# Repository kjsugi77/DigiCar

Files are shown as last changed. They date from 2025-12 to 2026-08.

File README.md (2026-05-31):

## 構成フォルダ
- program/        ← 車両制御プログラム（C++）
- electronics/    ← 基板データ（KiCad / Gerber / 回路図PDF）
- 3d_print/       ← 3Dプリント用データ（STL）
- parts/          ← 部品表（BOM）

---

# DigiCar（デジカー）

DigiCar は、ミニ四駆サイズの学習用自動運転ミニカーです。  
プリント基板そのものがシャーシとなる独自構造を採用し、  
RumiCar をリスペクトした教育向けプラットフォームとして開発されています。

2025年8月30日の「デジもく会」にて正式発表されました。

---

## 特徴

- プリント基板がシャーシとして機能する独自構造
- 自動運転機能を搭載予定（ToF センサ対応）
- Bluetooth をメインとした無線通信
- 教育教材としての普及を目指した低コスト設計（想定金額 約5,000円）

---

## システム構成

DigiCar は **電気系・プログラム・機械系** の 3 要素で構成されています。

### ● 電気系
- マイコン：ESP32-WROOM-32E  
- モータードライバ：TB6612FNG（東芝）  
- 電圧レギュレータ：TC1262-3.3VDB05（Microchip）  
- USBシリアル変換：FT231XS（FTDI）  
- 通信方式：Bluetooth（メイン）、Wi-Fi（サブ）

### ● プログラム
- 使用言語：C++（Arduino IDE）

### ● 機械系
- ステアリング：SG-90 サーボモータ  
- 駆動モータ：マブチ FA-130  
- ギア・シャフト・タイヤ：タミヤ製を中心に構成  
- 3Dプリント部品：ギヤケース、ステアリング機構、電池ケース固定部品など

---

## 開発ストーリー

### 2020年〜：胎動（暗黒時代）
N氏による構想が始まるも、具体化せず停滞。

### 2024年2月：運命の再始動
デジもく会で H氏の「基板、作りませんか？」の一言から再燃。

### 2025年3〜5月：継承と本格始動
京都NTで試作モックを受領し、開発が本格化。

### 2025年8〜9月：公開とコミュニティ化
初発表で手応えを掴み、はんだ付け会や Discord 開設へ。

### 2025年10〜11月：危機と復活
通信不良・異常電流の問題を発見。配線ミスを特定し、改良基板で復活。

### 2026年2月〜現在：次のステージへ
サンプル3台を提供し、マニュアル操作アプリも完成。  
現在は ToF センサ搭載による自動運転へ挑戦中。

---

## コスト構成（概算：ToF センサ除く 約 4,000 円）

### 1. 電気・電子部品（約 1,500 円）
- ESP32-WROOM-32E：約 800 円  
- FT231XS：約 320 円  
- TB6612FNG：約 200 円  
- その他：基板、抵抗・コンデンサ類

### 2. 駆動・メカ部品（約 1,000 円強）
- SG-90 サーボ：650 円  
- ギヤ・シャフト・タイヤ類：約 400 円  
- 3Dプリント部品、ネジ類

### 3. 電源（約 1,000 円強）
- エネループライト（単4×4本）：約 1,000 円  
- 電池ボックス（スイッチ付）：100 円

### 4. その他
- 基板（JLCPCB）：約 100 円

---

## ライセンス

本リポジトリは **MIT License** のもとで公開されています。

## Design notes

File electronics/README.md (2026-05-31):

# electronics フォルダについて

DigiCar の電装・基板データをまとめたフォルダです。  
基板設計（KiCad）、製造用データ（Gerber）、回路図（PDF）を用途別に整理しています。

## フォルダ構成

electronics/
├── kicad/               ← KiCad プロジェクト一式（.kicad_pcb / .sch など）
├── gerber/              ← 基板製造用データ（Gerber ファイル）
└── schematic/           ← 回路図（PDF など）

## 使い方

- **kicad/**  
  基板の編集・修正を行う場合に使用します。  
  KiCad でプロジェクトを開くと、回路図と PCB を編集できます。

- **gerber/**  
  基板製造業者にそのまま提出できるデータです。  
  製造依頼時はこのフォルダ内の ZIP を使用します。

- **schematic/**  
  回路図を PDF で確認したい場合に使用します。  
  アプリ開発者や他のメンバーが電装仕様を理解する際にも便利です。

# About the electronics folder

This folder contains all electronic and PCB-related data for the DigiCar project.  
The contents are organized by purpose: PCB design (KiCad), manufacturing data (Gerber), and circuit diagrams (PDF).

## Folder Structure

electronics/
├── kicad/               ← KiCad project files (.kicad_pcb / .sch, etc.)
├── gerber/              ← Manufacturing data for PCB fabrication (Gerber files)
└── schematic/           ← Circuit diagrams (PDF and related files)

## Usage

- **kicad/**  
  Use this folder when editing or modifying the PCB design.  
  Open the project in KiCad to edit both the schematic and PCB layout.

- **gerber/**  
  Contains the data required by PCB manufacturers.  
  When ordering a PCB, submit the ZIP file from this folder.

- **schematic/**  
  Use this folder to view the circuit diagrams in PDF format.  
  Helpful for app developers or team members who need to understand the electrical design.

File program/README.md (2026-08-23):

# DigiCar プログラム一覧

デジカー（DigiCar）を制御・操作するための各種ソフトウェアを管理しています。

## フォルダ構成

- **[esp32/](./esp32/)**
  - デジカー本体のマイコン（ESP32）用ファームウェア
  - Bluetooth/Wi-Fi直接操縦プログラム、および将来の自律制御・ROSノード（`ros/`）を配置
- **[android/](./android/)**
  - デジカー操作・監視用のAndroidアプリケーション
  - 直接操縦用アプリ、および将来の自律走行監視・ROS連携アプリ（`ros_controller/`）を配置

## 開発の進め方
1. **直接手動操縦:** `esp32/` 内のプログラムをESP32に書き込み、`android/` のアプリからBluetooth/Wi-Fiで操作します。
2. **自動化・ROS連携:** 将来的なmicro-ROS等による自律走行機能は各フォルダ内の `ros/` および `ros_controller/` にて拡張していきます。

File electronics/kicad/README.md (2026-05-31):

# kicad フォルダについて

このフォルダには、DigiCar の基板設計に使用している KiCad プロジェクトの主要ファイルが含まれています。  
回路図（schematic）と PCB レイアウト（pcb）を編集する際に使用します。

## 含まれるファイル

- **DigiCar.kicad_pro**  
  KiCad プロジェクトファイルです。  
  このファイルを開くことで、回路図エディタと PCB エディタを利用できます。

- **DigiCar.kicad_sch**  
  DigiCar の回路図データです。  
  電気的な接続、部品構成、信号ラインなどを編集できます。

- **DigiCar.kicad_pcb**  
  DigiCar の基板レイアウトデータです。  
  部品配置、配線、基板形状などを編集できます。

## 使い方

1. KiCad を起動し、**DigiCar.kicad_pro** を開きます。  
2. 回路図（Schematic Editor）または基板レイアウト（PCB Editor）を編集できます。

# About the kicad folder

This folder contains the main KiCad project files used for designing the DigiCar PCB.  
These files are used when editing the schematic and PCB layout.

## Included Files

- **DigiCar.kicad_pro**  
  The KiCad project file.  
  Opening this file allows you to access both the schematic editor and the PCB editor.

- **DigiCar.kicad_sch**  
  The schematic file for DigiCar.  
  You can edit electrical connections, component configuration, and signal lines.

- **DigiCar.kicad_pcb**  
  The PCB layout file for DigiCar.  
  You can edit component placement, routing, and the board outline.

## How to Use

1. Launch KiCad and open **DigiCar.kicad_pro**.  
2. Edit the schematic (Schematic Editor) or the PCB layout (PCB Editor) as needed.

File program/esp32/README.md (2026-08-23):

# DigiCar ESP32 Firmware

DigiCarのマイコン（ESP32）用ファームウェアを管理するフォルダです。

## 含まれるプログラム
- **DigiCar_BT.ino**: Bluetooth経由での手動操縦用プログラム
- **DigiCar_WiFi.ino**: Wi-Fi経由での手動操縦用プログラム
- **DigiCar_BT_APP_DEVELOPER_GUIDE.md**: Bluetooth通信プロトコル仕様書

## サブフォルダ
- **ros/**: micro-ROS / ROS 2ノード連携用のファームウェア

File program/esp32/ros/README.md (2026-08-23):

# DigiCar ESP32 ROS Node

DigiCarをROS 2ネットワークと連携させ、自律走行や高度な制御を行うためのESP32側プログラム（micro-ROS等）を管理します。

## 概要
- ROS 2のトピック（速度指令 `cmd_vel` など）をサブスクライブし、モータやサーボを制御
- センサー値やオドメトリなどのデータをROS 2ネットワークへパブリッシュ

## 開発ステータス
- 準備中 / 開発中

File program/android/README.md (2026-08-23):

# DigiCar Android App

DigiCarを操作・管理するためのAndroidアプリケーションを管理するフォルダです。

## 概要
- スマートフォンからBluetooth / Wi-Fiを介してDigiCarを直接手動操縦するためのアプリ
- プロジェクトソースコードおよび配布用APKを配置

## サブフォルダ
- **ros_controller/**: ROS 2連携・自律走行制御/モニタリング用アプリ

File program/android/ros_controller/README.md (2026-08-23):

# DigiCar ROS Controller App

ROS 2環境と連携してDigiCarの自律走行制御やステータス監視を行うAndroidアプリを管理します。

## 主な役割・機能（予定）
- 自律走行の開始 / 停止指令
- 目標地点（Waypoint）の送信や走行モード切り替え
- デジカーのセンサーデータ・走行ステータスのリアルタイムモニタリング
- 手動テレオペレーション（Teleop）介入機能

## 開発ステータス
- 準備中 / 開発中

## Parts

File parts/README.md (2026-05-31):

# parts フォルダについて

このフォルダには、DigiCar の部品情報（BOM: Bill of Materials）をまとめたファイルを保存しています。

## DigiCar_BOM_draft.pdf について

**DigiCar_BOM_draft.pdf** は、DigiCar の部品リストとして必要な情報が一通り揃っているものの、  
まだ最終的な確認（誤りの有無、見やすさの調整）が完了していないため、暫定版（draft）として保存しています。

内容の確認と整備が完了次第、正式版の **DigiCar_BOM.csv** として公開する予定です。

# About the parts folder

This folder contains files related to the DigiCar Bill of Materials (BOM).

## About DigiCar_BOM_draft.pdf

**DigiCar_BOM_draft.pdf** includes all the necessary information for the DigiCar parts list.  
However, it is saved as a draft version because the final checks—such as verifying for errors and improving readability—have not yet been completed.

Once the review and refinement are finished, it will be updated and released as the official **DigiCar_BOM.csv**.

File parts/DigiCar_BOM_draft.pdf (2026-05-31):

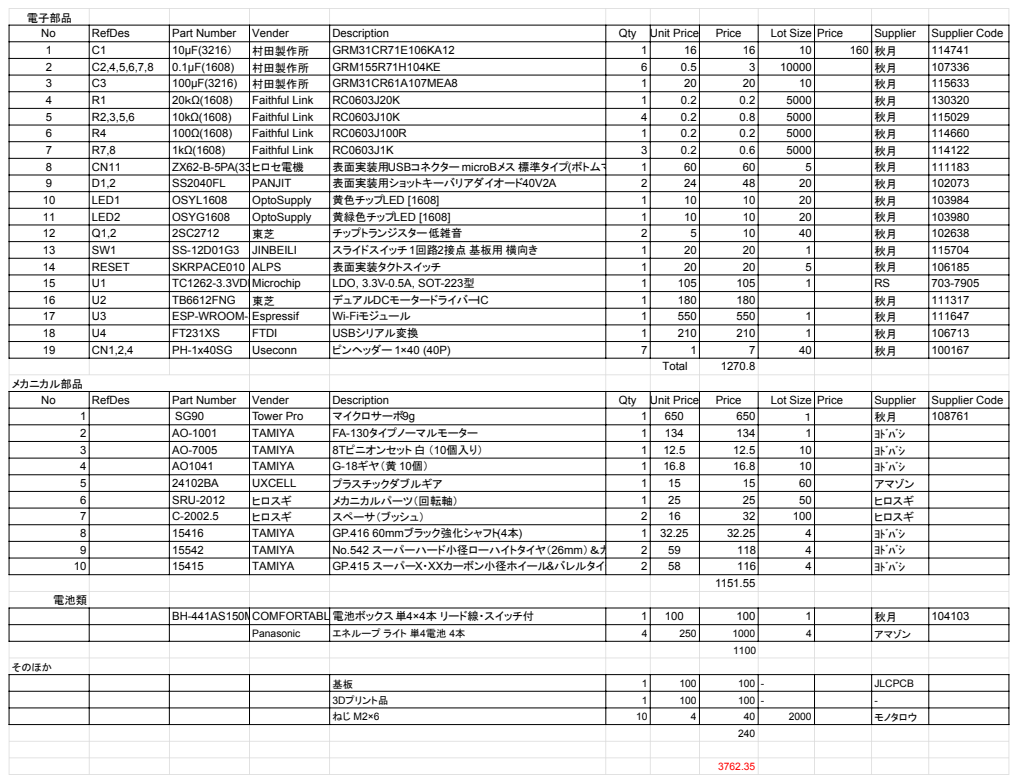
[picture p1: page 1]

No | RefDes | Part Number | Vender | Description | Qty | Unit Price | Price | Lot Size | Price | Supplier | Supplier Code
1 | C1 | 10μF(3216） | 村田製作所 | GRM31CR71E106KA12 | 1 | 16 | 16 | 10 | 160 | 秋月 | 114741
2 | C2,4,5,6,7,8 | 0.1μF(1608) | 村田製作所 | GRM155R71H104KE | 6 | 0.5 | 3 | 10000 | | 秋月 | 107336
3 | C3 | 100μF(3216) | 村田製作所 | GRM31CR61A107MEA8 | 1 | 20 | 20 | 10 | | 秋月 | 115633
4 | R1 | 20ｋΩ(1608) | Faithful Link | RC0603J20K | 1 | 0.2 | 0.2 | 5000 | | 秋月 | 130320
5 | R2,3,5,6 | 10kΩ(1608) | Faithful Link | RC0603J10K | 4 | 0.2 | 0.8 | 5000 | | 秋月 | 115029
6 | R4 | 100Ω(1608) | Faithful Link | RC0603J100R | 1 | 0.2 | 0.2 | 5000 | | 秋月 | 114660
7 | R7,8 | 1kΩ(1608) | Faithful Link | RC0603J1K | 3 | 0.2 | 0.6 | 5000 | | 秋月 | 114122
8 | CN11 | ZX62-B-5PA(33)ヒロセ電機 | | 表面実装用USBコネクター microBメス 標準タイプ(ボトムマウント1 | | 60 | 60 | 5 | | 秋月 | 111183
9 | D1,2 | SS2040FL | PANJIT | 表面実装用ショットキーバリアダイオード 40V2A | 2 | 24 | 48 | 20 | | 秋月 | 102073
10 | LED1 | OSYL1608 | OptoSupply | 黄色チップLED [1608] | 1 | 10 | 10 | 20 | | 秋月 | 103984
11 | LED2 | OSYG1608 | OptoSupply | 黄緑色チップLED [1608] | 1 | 10 | 10 | 20 | | 秋月 | 103980
12 | Q1,2 | 2SC2712 | 東芝 | チップトランジスター低雑音 | 2 | 5 | 10 | 40 | | 秋月 | 102638
13 | SW1 | SS-12D01G3 | JINBEILI | スライドスイッチ 1回路2接点 基板用 横向き | 1 | 20 | 20 | 1 | | 秋月 | 115704
14 | RESET | SKRPACE010 | ALPS | 表面実装タクトスイッチ | 1 | 20 | 20 | 5 | | 秋月 | 106185
15 | U1 | TC1262-3.3VDB05MP Microchip | | LDO, 3.3V-0.5A, SOT-223型 | 1 | 105 | 105 | 1 | | RS | 703-7905
16 | U2 | TB6612FNG | 東芝 | デュアルDCモータードライバーIC | 1 | 180 | 180 | | | 秋月 | 111317
17 | U3 | ESP-WROOM-32Espressif | | Wi-Fiモジュール | 1 | 550 | 550 | 1 | | 秋月 | 111647
18 | U4 | FT231XS | FTDI | USBシリアル変換 | 1 | 210 | 210 | 1 | | 秋月 | 106713
19 | CN1,2,4 | PH-1x40SG | Useconn | ピンヘッダー 1×40 (40P) | 7 | 1 | 7 | 40 | | 秋月 | 100167

1 | | SG90 | Tower Pro | マイクロサーボ9g | 1 | 650 | 650 | １ | | 秋月 | 108761
2 | | AO-1001 | TAMIYA | FA-130タイプノーマルモーター | 1 | 134 | 134 | 1 | | ﾖﾄﾞﾊﾞｼ
3 | | AO-7005 | TAMIYA | 8Tピニオンセット白 （10個入り） | 1 | 12.5 | 12.5 | 10 | | ﾖﾄﾞﾊﾞｼ
4 | | AO1041 | TAMIYA | G-18ギヤ（黄 10個） | 1 | 16.8 | 16.8 | 10 | | ﾖﾄﾞﾊﾞｼ
5 | | 24102BA | UXCELL | プラスチックダブルギア | 1 | 15 | 15 | 60 | | アマゾン
6 | | SRU-2012 | ヒロスギ | メカニカルパーツ（回転軸） | 1 | 25 | 25 | 50 | | ヒロスギ
7 | | C-2002.5 | ヒロスギ | スペーサ（ブッシュ） | 2 | 16 | 32 | 100 | | ヒロスギ
8 | | 15416 | TAMIYA | GP.416 60mmブラック強化シャフト(4本) | 1 | 32.25 | 32.25 | 4 | | ﾖﾄﾞﾊﾞｼ
9 | | 15542 | TAMIYA | No.542 スーパーハード小径ローハイトタイヤ（26mm）＆カーボン強化ホイール 2 | | 59 | 118 | 4 | | ﾖﾄﾞﾊﾞｼ
10 | | 15415 | TAMIYA | GP.415 スーパーX・XXカーボン小径ホイール&バレルタイヤ | 2 | 58 | 116 | 4 | | ﾖﾄﾞﾊﾞｼ

BH-441AS150MMCOMFORTABLE ELECTRONIC 電池ボックス単4×4本 リード線・スイッチ付 | | | 1 | 100 | 100 | 1 | 秋月 | 104103

Panasonic | エネループ ライト 単4電池 4本 | 4 | 250 | 1000 | 4 | アマゾン

基板 | 1 | 100 | 100 | - | JLCPCB
3Dプリント品 | 1 | 100 | 100 | - | -
ねじ M2×6 | 10 | 4 | 40 | 2000 | モノタロウ

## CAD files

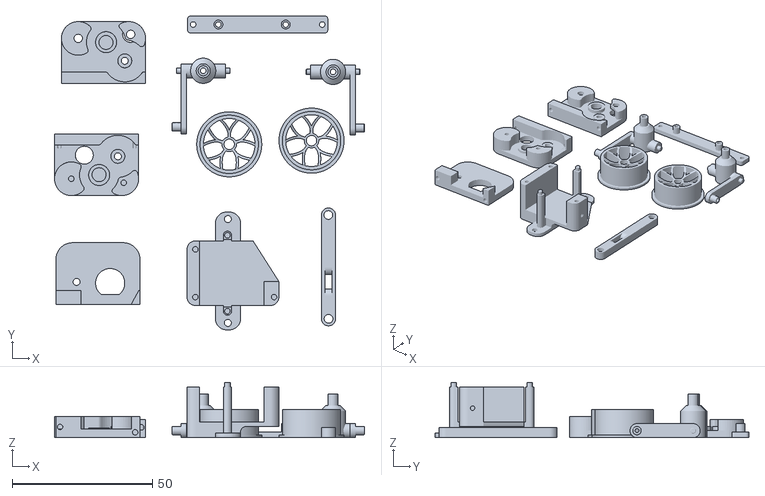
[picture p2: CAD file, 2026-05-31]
3d_print/DigiCar_AllSet.stl
110.5 x 111.9 x 19.7

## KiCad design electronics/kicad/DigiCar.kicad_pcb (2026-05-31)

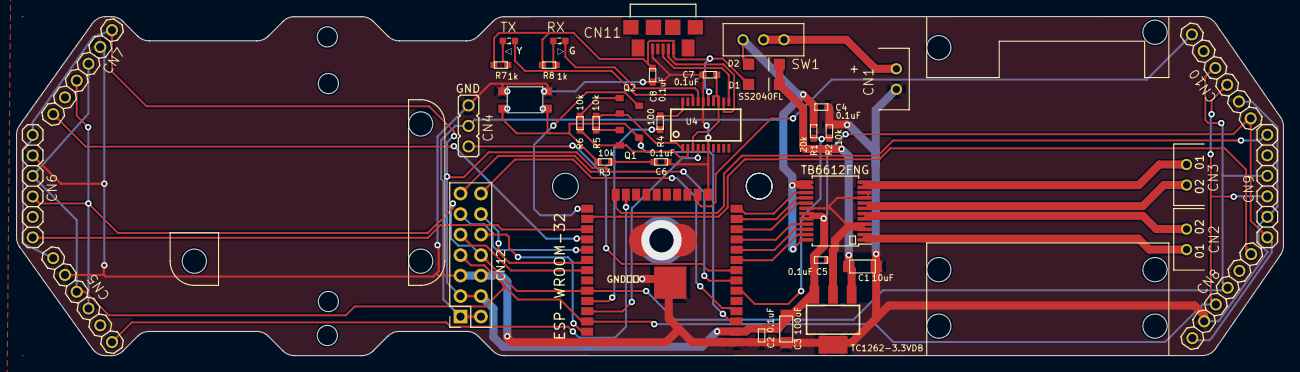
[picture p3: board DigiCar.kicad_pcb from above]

Board: 2 copper layers, 157.0 x 42.0 mm, 40 parts (0 on the bottom side), 48 nets.

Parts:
C1: 10uF; CP3216
C2, C4, C5, C6, C7, C8: 0.1uF; CP1608
C3: 100uF; CP3216
CN1, CN2, CN3: EH-2
CN4: PINHD-1X3; CON_RC_SERVO
CN5, CN6, CN7, CN8, CN9, CN10: PINHD-1X6; 1X06
CN11: ZX62-B-5PA(11); CONN_ZX62-B-5PA(11)_HIR
CN12: Conn_02x07_Odd_Even; PinSocket_2x07_P2.54mm_Vertical
D1, D2: SS2040FL; SOD123
ESP-WROOM-32: ESP-WROOM-32
Q1, Q2: 2SC2712; SC59
R1: 20k; CP1608
R2, R3, R5, R6: 10k; CP1608
R4: 100; CP1608
R7, R8: 1k; CP1608
RX: GREEN; LED1608
SW1: SS-12SDP2; SLIDE-SW
SW2: SKRPACE010
TB6612FNG: TB6612FNG; SSOP-24_5.3x8.2mm_P0.65mm
TC1262-3.3VDB: TC1262-3.3VDB; SOT223
TX: YELLOW; LED1608
U4: FT231XS; SSOP20

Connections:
+3V3: C2.SMD1 (PIN1), C3.SMD1 (PIN1), C5.SMD1 (PIN1), C6.SMD1 (PIN1), CN5.1, CN6.1, CN7.1, CN8.1, CN9.1, CN10.1, CN12.3, CN12.4, ESP-WROOM-32.2 (3V3), R3.SMD2 (PIN2), TB6612FNG.19 (STBY), TB6612FNG.20 (VCC), TC1262-3.3VDB.3 (VO)
/BATT_CHECK: ESP-WROOM-32.6 (IO34), R1.SMD1 (PIN1), R2.SMD2 (PIN2)
/BOOT: ESP-WROOM-32.25 (IO0), Q2.C
/IO5_SS: CN12.11, ESP-WROOM-32.29 (IO5)
/IO18_SCK: CN12.12, ESP-WROOM-32.30 (IO18)
/IO19_MISO: CN12.9, ESP-WROOM-32.31 (IO19)
/IO23_MOSI: CN12.10, ESP-WROOM-32.37 (IO23)
/IO35: CN12.13, ESP-WROOM-32.7 (IO35)
/IO36: CN12.14, ESP-WROOM-32.4 (SENSOR_VP)
/MOTOR_A_IN1: ESP-WROOM-32.11 (IO26), TB6612FNG.21 (AIN1)
/MOTOR_A_IN2: ESP-WROOM-32.10 (IO25), TB6612FNG.22 (AIN2)
/MOTOR_B_IN1: ESP-WROOM-32.12 (IO27), TB6612FNG.17 (BIN1)
/MOTOR_B_IN2: ESP-WROOM-32.13 (IO14), TB6612FNG.16 (BIN2)
/MOTOR_PWM_A: ESP-WROOM-32.9 (IO33), TB6612FNG.23 (PWMA)
/MOTOR_PWM_B: ESP-WROOM-32.14 (IO12), TB6612FNG.15 (PWMB)
/RESET: ESP-WROOM-32.3 (EN), Q1.C, R3.SMD1 (PIN1), SW2.1, SW2.2
/RXD: ESP-WROOM-32.34 (RXD0), R4.SMD2 (PIN2)
/RX_LED: RX.C, U4.17 (CBUS1)
/SCL: CN5.3, CN6.3, CN7.3, CN8.3, CN9.3, CN10.3, CN12.7, ESP-WROOM-32.36 (IO22)
/SDA: CN5.4, CN6.4, CN7.4, CN8.4, CN9.4, CN10.4, CN12.8, ESP-WROOM-32.33 (IO21)
/SERVO_PWM: CN4.1, ESP-WROOM-32.8 (IO32)
/TOF_SHDN0: CN5.6, ESP-WROOM-32.23 (IO15)
/TOF_SHDN1: CN6.6, ESP-WROOM-32.27 (IO16)
/TOF_SHDN2: CN7.6, ESP-WROOM-32.28 (IO17)
/TOF_SHDN3: CN8.6, ESP-WROOM-32.26 (IO4)
/TOF_SHDN4: CN9.6, ESP-WROOM-32.24 (IO2)
/TOF_SHDN5: CN10.6, ESP-WROOM-32.16 (IO13)
/TXD: ESP-WROOM-32.35 (TXD0), U4.4 (RXD)
/TX_LED: TX.C, U4.18 (CBUS0)
GND: C1.SMD2 (PIN2), C2.SMD2 (PIN2), C3.SMD2 (PIN2), C4.SMD2 (PIN2), C5.SMD2 (PIN2), C6.SMD2 (PIN2), C7.SMD2 (PIN2), C8.SMD2 (PIN2), CN1.2, CN4.3, CN5.2, CN6.2, CN7.2, CN8.2, CN9.2, CN10.2, CN11.5, CN12.5, CN12.6, ESP-WROOM-32.1 (GND@1), ESP-WROOM-32.15 (GND@2), ESP-WROOM-32.38 (GND@3), ESP-WROOM-32.GND (GND@4), R2.SMD1 (PIN1), SW2.3, SW2.4, TB6612FNG.3 (PGND1), TB6612FNG.4 (PGND1), TB6612FNG.9 (PGND2), TB6612FNG.10 (PGND2), TB6612FNG.18 (GND), TC1262-3.3VDB.2 (GND), TC1262-3.3VDB.4 (GND), U4.6 (GND@6), U4.16 (GND@16)
unnamed: C1.SMD1 (PIN1), D1.C, D2.C, TC1262-3.3VDB.1 (VI)
unnamed: C7.SMD1 (PIN1), U4.3 (VCCIO), U4.13 (3V3OUT), U4.14 (~RESET)
unnamed: CN2.1, TB6612FNG.1 (AO1), TB6612FNG.2 (AO1)
unnamed: CN2.2, TB6612FNG.5 (AO2), TB6612FNG.6 (AO2)
unnamed: CN3.1, TB6612FNG.7 (BO2), TB6612FNG.8 (BO2)
unnamed: CN3.2, TB6612FNG.11 (BO1), TB6612FNG.12 (BO1)
unnamed: R4.SMD1 (PIN1), U4.20 (TXD)
unnamed: Q2.E, R5.SMD1 (PIN1), U4.1 (~DTR)
unnamed: Q1.B, R5.SMD2 (PIN2)
unnamed: Q1.E, R6.SMD1 (PIN1), U4.2 (~RTS)
unnamed: Q2.B, R6.SMD2 (PIN2)
unnamed: R7.SMD1 (PIN1), TX.A
unnamed: R8.SMD1 (PIN1), RX.A
unnamed: CN1.1, SW1.2, SW1.3 (S)
unnamed: CN11.2, U4.12 (USBDM)
unnamed: CN11.3, U4.11 (USBDP)
VBUS: C8.SMD1 (PIN1), CN11.1, D1.A, R7.SMD2 (PIN2), R8.SMD2 (PIN2), U4.15 (VCC)
V_BATT: C4.SMD1 (PIN1), CN4.2, CN12.1, CN12.2, D2.A, R1.SMD2 (PIN2), SW1.1 (O), TB6612FNG.13 (VM2), TB6612FNG.14 (VM3), TB6612FNG.24 (VM1)

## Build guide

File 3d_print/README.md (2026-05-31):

# DigiCar_AllSet.stl について

**DigiCar_AllSet.stl** は、DigiCar を組み立てるために必要な 3D プリント部品をすべてまとめたデータです。  
すべてのオブジェクトを 1 つの STL ファイルにまとめています。

## 印刷について
- スライサーに読み込んで印刷できます。
- 必要に応じて、スライサー上でパーツを個別に分割して印刷してください。

# About DigiCar_AllSet.stl

**DigiCar_AllSet.stl** contains all the 3D‑printed parts required to assemble the DigiCar.  
All objects are combined into a single STL file.

## Printing Instructions
- Load the file into your slicer and print as needed.
- If necessary, separate the objects in the slicer and print them individually.

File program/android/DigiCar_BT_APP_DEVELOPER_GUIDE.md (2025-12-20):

# DigiCar Bluetooth API リファレンス

## 概要

この文書は、DigiCar（ESP32ベースのロボットカー）をBluetooth経由で制御するためのAPI仕様書です。  
アプリ開発者がDigiCarと通信する際のプロトコル、コマンド形式、実装方法を説明します。

---

## 目次

1. [デバイス情報](#デバイス情報)
2. [接続方法](#接続方法)
3. [通信プロトコル](#通信プロトコル)
4. [コマンド仕様](#コマンド仕様)
5. [応答形式](#応答形式)
6. [実装例](#実装例)
7. [エラーハンドリング](#エラーハンドリング)
8. [注意事項](#注意事項)

---

## デバイス情報

### Bluetoothデバイス名
```
DigiCar_Control
```

### デバイスタイプ
- **プロトコル**: Bluetooth Classic (SPP - Serial Port Profile)
- **ペアリング**: 不要（接続のみ）
- **認証**: なし

### 対応プラットフォーム
- Android (BluetoothAdapter)
- iOS (CoreBluetooth - 注意: iOSはBluetooth Classicの制限あり)
- Windows (Bluetooth Serial)
- Linux (Bluetooth Serial)

---

## 接続方法

### 1. デバイス検索
Bluetoothデバイス一覧から `DigiCar_Control` を検索します。

### 2. 接続
- **ペアリング**: 不要
- **認証**: 不要
- **接続後**: すぐにコマンド送信可能

### 3. 切断
通常のBluetooth切断手順で切断できます。

---

## 通信プロトコル

### 文字エンコーディング
- **形式**: UTF-8
- **改行文字**: `\n` (LF, 0x0A)
- **文字列終端**: 改行文字で終了

### 送信形式
```
<コマンド>\n
```

### 受信形式
```
OK\n
```

### 通信フロー
```
アプリ → DigiCar: <コマンド>\n
DigiCar → アプリ: OK\n
```

---

## コマンド仕様

### 基本形式
すべてのコマンドは改行文字（`\n`）で終了します。

### コマンド一覧

| コマンド | 形式 | 説明 |
|---|---|---|
| **前進** | `F<speed>` | 指定速度で前進 |
| **後退** | `B<speed>` | 指定速度で後退 |
| **停止** | `S` | モーターを停止 |
| **ステアリング** | `T<angle>` | ステアリング角度を設定 |
| **ジョイスティック** | `J<speed>,<steering>,<direction>` | 速度・ステアリング・方向を同時に設定 |

---

### 1. 前進コマンド

#### 形式
```
F<speed>\n
```

#### パラメータ
- **speed**: 速度（0-100の整数）
  - `0`: 停止
  - `1-100`: 速度パーセンテージ

#### 例
```
F50\n    → 50%速度で前進
F100\n   → 100%速度で前進
F0\n     → 停止（無効、Sコマンドを使用）
```

#### 動作
- 速度が `0` または `100` を超える場合、コマンドは無視されます
- 有効な速度範囲: `1-100`

---

### 2. 後退コマンド

#### 形式
```
B<speed>\n
```

#### パラメータ
- **speed**: 速度（0-100の整数）
  - `0`: 停止
  - `1-100`: 速度パーセンテージ

#### 例
```
B50\n    → 50%速度で後退
B80\n    → 80%速度で後退
```

#### 動作
- 速度が `0` または `100` を超える場合、コマンドは無視されます
- 有効な速度範囲: `1-100`

---

### 3. 停止コマンド

#### 形式
```
S\n
```

#### パラメータ
なし

#### 例
```
S\n      → モーターを停止
```

#### 動作
- モーターA、モーターBの両方を即座に停止します
- PWM信号を0に設定します

---

### 4. ステアリングコマンド

#### 形式
```
T<angle>\n
```

#### パラメータ
- **angle**: ステアリング角度（60-120の整数）
  - `60`: 左端
  - `90`: 中央
  - `120`: 右端

#### 例
```
T90\n    → ステアリングを中央に
T60\n    → ステアリングを左端に
T120\n   → ステアリングを右端に
```

#### 動作
- 角度が `60` 未満の場合、`60` に制限されます
- 角度が `120` を超える場合、`120` に制限されます
- 有効な角度範囲: `60-120`

---

### 5. ジョイスティックコマンド

#### 形式
```
J<speed>,<steering>,<direction>\n
```

#### パラメータ
- **speed**: 速度（0-100の整数）
  - `0-5`: 自動停止
  - `6-100`: 速度パーセンテージ
- **steering**: ステアリング角度（60-120の整数）
  - `60`: 左端
  - `90`: 中央
  - `120`: 右端
- **direction**: 方向（文字列）
  - `"前進"` または `"forward"` または `"F"`: 前進
  - `"後進"` または `"backward"` または `"B"`: 後退
  - その他: デフォルトで前進

#### 例
```
J50,90,前進\n        → 速度50%, ステアリング90度（中央）, 前進
J80,120,backward\n   → 速度80%, ステアリング120度（右端）, 後退
J30,60,F\n          → 速度30%, ステアリング60度（左端）, 前進
J0,90,前進\n        → 停止（speed <= 5）
```

#### 動作
- 速度が `5` 以下の場合、自動的に停止します
- ステアリング角度が範囲外の場合、無視されます
- 方向が認識できない場合、デフォルトで前進します

---

## 応答形式

### 成功応答
すべてのコマンドに対して、成功時は以下の応答が返されます：
```
OK\n
```

### 応答のタイミング
- コマンド受信後、処理完了時に応答を送信します
- 応答は即座に返されます（通常、数ミリ秒以内）

### エラー応答
- 無効なコマンドの場合でも `OK\n` が返されます
- コマンドが無視された場合でも `OK\n` が返されます
- タイムアウトが発生した場合、応答が返らない可能性があります

---

## 実装例

### Android (Java/Kotlin)

#### 接続
```java
import android.bluetooth.BluetoothAdapter;
import android.bluetooth.BluetoothDevice;
import android.bluetooth.BluetoothSocket;
import java.io.OutputStream;
import java.io.InputStream;
import java.util.UUID;

// Bluetooth接続
BluetoothAdapter adapter = BluetoothAdapter.getDefaultAdapter();
BluetoothDevice device = adapter.getRemoteDevice("デバイスのMACアドレス");
UUID uuid = UUID.fromString("00001101-0000-1000-8000-00805F9B34FB"); // SPP UUID
BluetoothSocket socket = device.createRfcommSocketToServiceRecord(uuid);
socket.connect();

OutputStream outputStream = socket.getOutputStream();
InputStream inputStream = socket.getInputStream();
```

#### コマンド送信
```java
// 前進コマンド送信
String command = "F50\n";
outputStream.write(command.getBytes("UTF-8"));

// 応答受信
byte[] buffer = new byte[1024];
int bytes = inputStream.read(buffer);
String response = new String(buffer, 0, bytes, "UTF-8");
// response = "OK\n"
```

#### ジョイスティックコマンド送信
```java
// ジョイスティックコマンド送信
int speed = 50;
int steering = 90;
String direction = "前進";
String command = String.format("J%d,%d,%s\n", speed, steering, direction);
outputStream.write(command.getBytes("UTF-8"));
```

---

### iOS (Swift)

#### 注意事項
iOSはBluetooth Classicの制限があるため、`ExternalAccessory` フレームワークを使用する必要があります。  
または、BLE（Bluetooth Low Energy）への移行を検討してください。

#### 接続（CoreBluetooth使用 - BLE推奨）
```swift
import CoreBluetooth

// BLEへの移行を推奨
// または ExternalAccessory フレームワークを使用
```

---

### Python (Windows/Linux)

#### 接続
```python
import bluetooth

# デバイス検索
devices = bluetooth.discover_devices()
target_device = None
for addr in devices:
    name = bluetooth.lookup_name(addr)
    if name == "DigiCar_Control":
        target_device = addr
        break

# 接続
socket = bluetooth.BluetoothSocket(bluetooth.RFCOMM)
socket.connect((target_device, 1))
```

#### コマンド送信
```python
# 前進コマンド送信
command = "F50\n"
socket.send(command.encode('utf-8'))

# 応答受信
response = socket.recv(1024).decode('utf-8')
# response = "OK\n"
```

#### ジョイスティックコマンド送信
```python
# ジョイスティックコマンド送信
speed = 50
steering = 90
direction = "前進"
command = f"J{speed},{steering},{direction}\n"
socket.send(command.encode('utf-8'))
```

---

### JavaScript (Web Bluetooth API)

#### 注意事項
Web Bluetooth APIは一部のブラウザ（Chrome、Edge）でのみサポートされています。

#### 接続
```javascript
// Web Bluetooth APIを使用
navigator.bluetooth.requestDevice({
    filters: [{ name: 'DigiCar_Control' }],
    optionalServices: ['00001101-0000-1000-8000-00805F9B34FB']
})
.then(device => device.gatt.connect())
.then(server => server.getPrimaryService('00001101-0000-1000-8000-00805F9B34FB'))
.then(service => service.getCharacteristic('...'))
.then(characteristic => {
    // コマンド送信
    const command = "F50\n";
    const encoder = new TextEncoder();
    characteristic.writeValue(encoder.encode(command));
});
```

---

## エラーハンドリング

### タイムアウト
- コマンド送信後、5秒以内に応答がない場合、タイムアウトとみなします
- タイムアウト時は、再接続を試みることを推奨します

### 無効なコマンド
- 無効なコマンド形式の場合、コマンドは無視されますが、`OK\n` が返されます
- アプリ側でコマンド形式を検証することを推奨します

### 接続エラー
- 接続が切断された場合、自動再接続機能を実装することを推奨します
- 定期的に接続状態を確認してください

### パラメータ範囲外
- 速度が `0` または `100` を超える場合、コマンドは無視されます
- ステアリング角度が `60-120` の範囲外の場合、範囲内に制限されます
- アプリ側でパラメータを検証することを推奨します

---

## 注意事項

### 1. コマンド送信頻度
- コマンド送信頻度は **10Hz（100ms間隔）** 以下を推奨します
- 過度な送信は、ESP32の処理負荷を増加させる可能性があります

### 2. 文字エンコーディング
- 必ず **UTF-8** エンコーディングを使用してください
- 日本語文字列（"前進"、"後進"）を使用する場合は、UTF-8でエンコードしてください

### 3. 改行文字
- コマンドの終端には必ず **改行文字（`\n`）** を含めてください
- 改行文字がない場合、コマンドは認識されません

### 4. 同時コマンド
- 複数のコマンドを同時に送信しないでください
- 1つのコマンドを送信し、応答を待ってから次のコマンドを送信してください

### 5. ステアリング制御
- ステアリングは非ブロッキング方式で制御されています
- ステアリングコマンドを送信しても、即座に角度が変わるわけではありません
- サーボモーターの応答時間を考慮してください（通常、数百ミリ秒）

### 6. モーター制御
- モーターの速度はPWM信号で制御されています
- 速度変更は即座に反映されます
- 停止コマンド（`S`）を送信すると、モーターは即座に停止します

### 7. iOSの制限
- iOSはBluetooth Classicの制限があるため、`ExternalAccessory` フレームワークを使用する必要があります
- または、BLE（Bluetooth Low Energy）への移行を検討してください

### 8. デバッグ
- デバッグ時は、シリアルモニターでコマンドの受信を確認できます
- ESP32のシリアル出力（115200 baud）でコマンドの処理状況を確認できます

---

## コマンド一覧表（クイックリファレンス）

| コマンド | 形式 | パラメータ | 例 |
|---|---|---|-----|
| **前進** | `F<speed>` | speed: 1-100 | `F50\n` |
| **後退** | `B<speed>` | speed: 1-100 | `B50\n` |
| **停止** | `S` | なし | `S\n` |
| **ステアリング** | `T<angle>` | angle: 60-120 | `T90\n` |
| **ジョイスティック** | `J<speed>,<steering>,<direction>` | speed: 0-100, steering: 60-120, direction: "前進"/"後進" | `J50,90,前進\n` |

---

## バージョン情報

- **API Version**: 1.0
- **最終更新**: 2025年12月
- **対応ファームウェア**: 20251206 DigiCar.ino

---

## サポート

問題や質問がある場合は、プロジェクトのリポジトリにIssueを登録してください。

---

## ライセンス

このAPI仕様書は、DigiCarプロジェクトの一部です。

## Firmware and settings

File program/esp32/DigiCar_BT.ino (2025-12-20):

#include "BluetoothSerial.h"

#if !defined(CONFIG_BT_ENABLED) || !defined(CONFIG_BLUEDROID_ENABLED)
#error Bluetooth is not enabled! Please run `make menuconfig` to and enable it
#endif

// デバッグ出力の制御
#define DEBUG_SERIAL 1  // 0: 無効化、1: 有効化

// モーター制御ピン（TB6612FNG）
#define MOTOR_A_IN1  26  // GPIO26
#define MOTOR_A_IN2  25  // GPIO25
#define MOTOR_A_PWM  33  // GPIO33
#define MOTOR_B_IN1  27  // GPIO27
#define MOTOR_B_IN2  14  // GPIO14
#define MOTOR_B_PWM  12  // GPIO12

// サーボモーター制御ピン（ステアリング）
#define SERVO_PIN    32  // GPIO32

// Bluetooth設定
BluetoothSerial SerialBT;
const char* deviceName = "DigiCar_Control";

void setup() {
  Serial.begin(115200);
  #if DEBUG_SERIAL
  Serial.println("=== DigiCar Steering Control (Simple) ===");
  #endif
  
  // CPU周波数を下げて発熱を軽減
  setCpuFrequencyMhz(80);
  #if DEBUG_SERIAL
  Serial.print("CPU Frequency: ");
  Serial.print(getCpuFrequencyMhz());
  Serial.println(" MHz");
  #endif
  
  // モーター制御ピンの設定
  pinMode(MOTOR_A_IN1, OUTPUT);
  pinMode(MOTOR_A_IN2, OUTPUT);
  pinMode(MOTOR_A_PWM, OUTPUT);
  pinMode(MOTOR_B_IN1, OUTPUT);
  pinMode(MOTOR_B_IN2, OUTPUT);
  pinMode(MOTOR_B_PWM, OUTPUT);
  
  // サーボピンの設定
  pinMode(SERVO_PIN, OUTPUT);
  
  // 初期状態：停止
  stopMotors();
  setServoAngle(90); // サーボを中央位置に
  #if DEBUG_SERIAL
  Serial.println("Motors and Steering initialized");
  #endif
  
  // Bluetooth起動
  SerialBT.begin(deviceName);
  #if DEBUG_SERIAL
  Serial.println("Bluetooth started");
  Serial.print("Device Name: ");
  Serial.println(deviceName);
  Serial.println("Commands: F<speed>, B<speed>, S, T<angle>, J<speed>,<steering>,<direction>");
  #endif
}

void loop() {
  // Bluetooth通信を処理
  if (SerialBT.available()) {
    String command = SerialBT.readStringUntil('\n');
    command.trim(); // 前後の空白文字（スペース、タブ、改行など）を削除
    
    #if DEBUG_SERIAL
    Serial.print("Received: ");
    Serial.println(command);
    #endif
    
    parseCommand(command); // コマンドを解析して実行
  }
  
  // サーボ制御を非同期で実行
  updateServoAsync();
  
  yield();
}

// サーボ角度設定関数（ステアリング）- 非ブロッキング方式
static int currentServoAngle = 90;

void setServoAngle(int angle) {
  // 角度を60～120度の範囲に制限
  if (angle < 60) angle = 60;
  if (angle > 120) angle = 120;
  currentServoAngle = angle;
}

// サーボ制御を非同期で実行（非ブロッキング方式）
// 20msごとにパルスを送信して、Bluetooth通信をブロックしない
void updateServoAsync() {
  static unsigned long lastPulse = 0;
  unsigned long now = millis();
  
  // 20msごとにパルスを送信（50Hz）
  if (now - lastPulse >= 20) {
    lastPulse = now;
    // 角度をパルス幅に変換（0度=500us, 180度=2500us）
    int pulseWidth = map(currentServoAngle, 0, 180, 500, 2500);
    digitalWrite(SERVO_PIN, HIGH);
    delayMicroseconds(pulseWidth);
    digitalWrite(SERVO_PIN, LOW);
  }
}

// Bluetoothコマンド解析関数
// コマンド形式: F<speed>, B<speed>, S, T<angle>, J<speed>,<steering>,<direction>
void parseCommand(String command) {
  if (command.length() == 0) return;
  
  char cmd = command.charAt(0);
  
  if (cmd == 'F' || cmd == 'f') {
    // 前進: F<speed> (例: F50 = 50%速度で前進)
    int speed = command.substring(1).toInt();
    if (speed > 0 && speed <= 100) {
      moveForwardWithSpeed(speed);
      #if DEBUG_SERIAL
      Serial.print("Forward: ");
      Serial.println(speed);
      #endif
    }
  } else if (cmd == 'B' || cmd == 'b') {
    // 後退: B<speed> (例: B50 = 50%速度で後退)
    int speed = command.substring(1).toInt();
    if (speed > 0 && speed <= 100) {
      moveBackwardWithSpeed(speed);
      #if DEBUG_SERIAL
      Serial.print("Backward: ");
      Serial.println(speed);
      #endif
    }
  } else if (cmd == 'S' || cmd == 's') {
    // 停止: S
    stopMotors();
    #if DEBUG_SERIAL
    Serial.println("Stop");
    #endif
  } else if (cmd == 'T' || cmd == 't') {
    // ステアリング: T<angle> (例: T90 = 中央, T60 = 左端, T120 = 右端)
    int angle = command.substring(1).toInt();
    if (angle >= 60 && angle <= 120) {
      setServoAngle(angle);
      #if DEBUG_SERIAL
      Serial.print("Steering: ");
      Serial.println(angle);
      #endif
    }
  } else if (cmd == 'J' || cmd == 'j') {
    // ジョイスティック: J<speed>,<steering>,<direction>
    // 例: J50,90,前進 = 速度50%, ステアリング90度, 前進方向
    int firstComma = command.indexOf(',');
    int secondComma = command.indexOf(',', firstComma + 1);
    
    if (firstComma > 0 && secondComma > firstComma) {
      int speed = command.substring(1, firstComma).toInt();
      int steering = command.substring(firstComma + 1, secondComma).toInt();
      String direction = command.substring(secondComma + 1);
      
      if (steering >= 60 && steering <= 120) {
        setServoAngle(steering);
      }
      
      if (speed > 5) {
        if (direction == "前進" || direction == "forward" || direction == "F") {
          moveForwardWithSpeed(speed);
        } else if (direction == "後進" || direction == "backward" || direction == "B") {
          moveBackwardWithSpeed(speed);
        } else {
          moveForwardWithSpeed(speed); // デフォルトは前進
        }
      } else {
        stopMotors();
      }
      
      #if DEBUG_SERIAL
      Serial.print("Joystick: speed=");
      Serial.print(speed);
      Serial.print(", steering=");
      Serial.print(steering);
      Serial.print(", direction=");
      Serial.println(direction);
      #endif
    }
  }
  
  SerialBT.println("OK");
}

// モーター制御関数（PWM速度制御）
void moveForwardWithSpeed(int speedPercent) {
  // 速度をPWM値に変換（0-100% → 0-255）
  int pwmValue = map(speedPercent, 0, 100, 0, 255);
  
  // Motor A: 前進
  digitalWrite(MOTOR_A_IN1, HIGH);
  digitalWrite(MOTOR_A_IN2, LOW);
  analogWrite(MOTOR_A_PWM, pwmValue);
  
  // Motor B: 前進
  digitalWrite(MOTOR_B_IN1, HIGH);
  digitalWrite(MOTOR_B_IN2, LOW);
  analogWrite(MOTOR_B_PWM, pwmValue);
  
  yield();
}

void moveBackwardWithSpeed(int speedPercent) {
  // 速度をPWM値に変換（0-100% → 0-255）
  int pwmValue = map(speedPercent, 0, 100, 0, 255);
  
  // Motor A: 後退
  digitalWrite(MOTOR_A_IN1, LOW);
  digitalWrite(MOTOR_A_IN2, HIGH);
  analogWrite(MOTOR_A_PWM, pwmValue);
  
  // Motor B: 後退
  digitalWrite(MOTOR_B_IN1, LOW);
  digitalWrite(MOTOR_B_IN2, HIGH);
  analogWrite(MOTOR_B_PWM, pwmValue);
  
  yield();
}

void stopMotors() {
  #if DEBUG_SERIAL
  Serial.println("Stop motors");
  #endif
  
  digitalWrite(MOTOR_A_IN1, LOW);
  digitalWrite(MOTOR_A_IN2, LOW);
  analogWrite(MOTOR_A_PWM, 0);
  
  digitalWrite(MOTOR_B_IN1, LOW);
  digitalWrite(MOTOR_B_IN2, LOW);
  analogWrite(MOTOR_B_PWM, 0);
}

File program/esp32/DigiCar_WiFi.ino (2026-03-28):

#include <WiFi.h>
#include <WebServer.h>
#include <esp_wifi.h>

// 正しいモーター制御ピン
#define MOTOR_A_IN1  26  // GPIO26
#define MOTOR_A_IN2  25  // GPIO25
#define MOTOR_A_PWM  33  // GPIO33
#define MOTOR_B_IN1  27  // GPIO27
#define MOTOR_B_IN2  14  // GPIO14
#define MOTOR_B_PWM  12  // GPIO12

// サーボモーター制御ピン（ステアリング）
#define SERVO_PIN    32  // GPIO32（サーボ信号線）

// WiFi設定
const char* password = "digimoku";     // WiFiのパスワード
String ssid;                           // SSIDは起動時にMACアドレスから生成

WebServer server(80);

void setup() {
  Serial.begin(115200);
  Serial.println("=== DigiCar Steering Control (Simple) ===");
  
  // CPU周波数を下げて発熱を軽減
  setCpuFrequencyMhz(80); // 240MHz → 80MHz
  Serial.print("CPU Frequency: ");
  Serial.print(getCpuFrequencyMhz());
  Serial.println(" MHz");
  
  // モーター制御ピンの設定
  pinMode(MOTOR_A_IN1, OUTPUT);
  pinMode(MOTOR_A_IN2, OUTPUT);
  pinMode(MOTOR_A_PWM, OUTPUT);
  pinMode(MOTOR_B_IN1, OUTPUT);
  pinMode(MOTOR_B_IN2, OUTPUT);
  pinMode(MOTOR_B_PWM, OUTPUT);
  
  // サーボピンの設定
  pinMode(SERVO_PIN, OUTPUT);
  
  // 初期状態：停止
  stopMotors();
  setServoAngle(90); // サーボを中央位置に
  Serial.println("Motors and Steering initialized");

  // MACアドレス下4桁をSSIDに付加（例: DigiCar_Control_B65D）
  // APモードで起動してからMACアドレスを取得
  WiFi.softAP("DigiCar_Control", password); // 仮SSIDで一旦起動
  String mac = WiFi.softAPmacAddress();     // APモードのMACアドレスを取得
  mac.replace(":", "");                     // コロン除去 → "A4CF12B65Dxx"
  String macSuffix = mac.substring(mac.length() - 6, mac.length() - 2); // 下2バイト = 4文字
  macSuffix.toUpperCase();
  ssid = "DigiCar_Control_" + macSuffix;

  // 正式なSSIDで再起動
  WiFi.softAP(ssid.c_str(), password);
  
  // WiFi省電力設定
  WiFi.setSleep(false); // WiFiスリープを無効化（安定性優先）
  
  // 省電力設定（安全な方法）
  #ifdef ESP32
    esp_wifi_set_ps(WIFI_PS_NONE); // WiFi省電力モードを無効化
  #endif
  
  // 起動時にシリアルへ接続情報を表示
  Serial.println("========================================");
  Serial.println("  WiFi AP started");
  Serial.print  ("  SSID     : ");
  Serial.println(ssid);
  Serial.print  ("  Password : ");
  Serial.println(password);
  Serial.print  ("  IP       : ");
  Serial.println(WiFi.softAPIP());
  Serial.println("  ブラウザで http://192.168.4.1 を開いてね！");
  Serial.println("========================================");
  
  // Webサーバーの設定
  server.on("/", handleRoot);
  server.on("/forward", handleForward);
  server.on("/backward", handleBackward);
  server.on("/stop", handleStop);
  server.on("/steering", handleSteering);
  server.on("/joystick", handleJoystick);
  
  server.begin();
  Serial.println("Web server started");
}

void loop() {
  server.handleClient();
  delay(10); // 適切な遅延でCPU負荷を軽減
}

// サーボ角度設定関数（ステアリング）- 最適化版
void setServoAngle(int angle) {
  // 角度をパルス幅に変換（0度=500us, 180度=2500us）
  int pulseWidth = map(angle, 0, 180, 500, 2500);
  
  // サーボパルスを送信（1回のみ）
  digitalWrite(SERVO_PIN, HIGH);
  delayMicroseconds(pulseWidth);
  digitalWrite(SERVO_PIN, LOW);
}

// WebページのHTML
void handleRoot() {
  String html = R"html(
<!DOCTYPE html>
<html lang="ja">
<head>
    <meta charset="UTF-8">
    <meta name="viewport" content="width=device-width, initial-scale=1.0">
    <title>DigiCar Steering Control</title>
    <style>
        body {
            font-family: Arial, sans-serif;
            text-align: center;
            background-color: #f0f0f0;
            margin: 0;
            padding: 20px;
            /* テキスト選択を無効化 */
            -webkit-user-select: none;
            user-select: none;
        }
        .container {
            max-width: 400px;
            margin: 0 auto;
            background: white;
            padding: 20px;
            border-radius: 10px;
            box-shadow: 0 2px 10px rgba(0,0,0,0.1);
        }
        h1 {
            color: #333;
            margin-bottom: 30px;
        }
        .control-grid {
            display: flex;
            flex-direction: column;
            gap: 10px;
            margin-bottom: 30px;
            align-items: center;
        }
        .control-btn {
            padding: 25px;
            font-size: 20px;
            border: none;
            border-radius: 10px;
            cursor: pointer;
            transition: all 0.1s;
            font-weight: bold;
            /* タップ時のハイライト無効化 */
            -webkit-tap-highlight-color: transparent;
            touch-action: none;
        }
        .forward { 
            background-color: #4CAF50; 
            color: white; 
            width: 80%;
        }
        .backward { 
            background-color: #f44336; 
            color: white; 
            width: 80%;
        }
        .stop { 
            background-color: #9E9E9E; 
            color: white; 
            width: 100%; 
        }
        .control-btn:active, .control-btn.pressed {
            transform: scale(0.95);
            filter: brightness(0.85);
        }
        
        .steering-section {
            margin-bottom: 20px;
        }
        .steering-label {
            font-size: 18px;
            font-weight: bold;
            margin-bottom: 10px;
            color: #333;
        }
        .steering-slider {
            width: 100%;
            height: 40px;
            -webkit-appearance: none;
            appearance: none;
            background: #ddd;
            outline: none;
            border-radius: 20px;
            margin-bottom: 10px;
        }
        .steering-slider::-webkit-slider-thumb {
            -webkit-appearance: none;
            appearance: none;
            width: 50px;
            height: 50px;
            background: #2196F3;
            cursor: pointer;
            border-radius: 50%;
            border: 3px solid white;
            box-shadow: 0 2px 5px rgba(0,0,0,0.2);
        }
        .steering-slider::-moz-range-thumb {
            width: 50px;
            height: 50px;
            background: #2196F3;
            cursor: pointer;
            border-radius: 50%;
            border: 3px solid white;
            box-shadow: 0 2px 5px rgba(0,0,0,0.2);
        }
        .steering-value {
            font-size: 16px;
            color: #666;
            margin-bottom: 20px;
        }
        
        .status {
            margin-top: 20px;
            padding: 10px;
            background-color: #e8f5e8;
            border-radius: 5px;
            color: #2e7d32;
        }
        
        .joystick-section {
            margin-top: 20px;
        }
        
        .joystick-container {
            position: relative;
            width: 150px;
            height: 150px;
            margin: 0 auto 15px;
            background: radial-gradient(circle, #e0e0e0 0%, #c0c0c0 100%);
            border-radius: 50%;
            border: 2px solid #999;
            box-shadow: inset 0 2px 10px rgba(0,0,0,0.1);
            cursor: pointer;
            touch-action: none;
        }
        
        .joystick-knob {
            position: absolute;
            width: 40px;
            height: 40px;
            background: linear-gradient(145deg, #4CAF50, #45a049);
            border-radius: 50%;
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
